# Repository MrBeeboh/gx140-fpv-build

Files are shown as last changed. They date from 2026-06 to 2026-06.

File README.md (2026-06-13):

# FPV Drone Fleet Project — Master Index
**Location:** `/home/mike/projects/Drone Projects/`
**Generated:** 2025-12-12
**Last Updated:** 2025-12-12
**Verification:** Claude Code `--chrome` researcher validated SBC/motor/GPS/radio dimensions against manufacturer wikis, DXF files, and datasheets. Mounting patterns corrected (Matek 25×25 M2, Rock 5C 86×56mm).

---

## DIRECTORY STRUCTURE

```
/home/mike/projects/Drone Projects/
├── inventory/
│   └── fleet_inventory.md          # Complete parts inventory (119 line items)
├── sbc/
│   └── sbc_deployment_checklist.md # SBC companion computer deployment
├── hardware/
│   └── hardware_reference.md       # Dimensions, pinouts, fitment data
├── cad/
│   └── mounts.scad                 # OpenSCAD parametric mounts
├── wiring/
│   └── wiring_diagrams.md          # Pin-to-pin tables, KiCad netlist
├── assembly/
│   └── assembly_sheets.md          # Step-by-step build sheets
└── docs/
    └── (future: flight logs, tuning notes, etc.)
```

---

## QUICK NAVIGATION

### Inventory & Status
| Document | Purpose | Key Data |
|---|---|---|
| `inventory/fleet_inventory.md` | Complete BOM | 6 builds, 119 items, gaps, priority orders |
| `inventory/fleet_inventory.md` | Walksnail ecosystem | Complete (Avatar Pro, Mini 1S, Goggles X, Patch V2) |

### SBC Companion Computers
| Document | Purpose | Key Data |
|---|---|---|
| `sbc/sbc_deployment_checklist.md` | Deploy Rock 5C ×2, Zero 3W, VIM4 | Hardware, software, power, cooling, model perf |

### Mechanical & CAD
| Document | Purpose | Key Data |
|---|---|---|
| `cad/mounts.scad` | 3D printable mounts | Rock 5C, Zero 3W, VIM4, cameras, wire channels |
| `hardware/hardware_reference.md` | Fitment bible | All dims, pinouts, clearance rules, thermal limits |

### Electrical & Wiring
| Document | Purpose | Key Data |
|---|---|---|
| `wiring/wiring_diagrams.md` | Wire-by-wire | SBC↔FC UART, power distro, KiCad netlist, test matrix |

### Build Instructions
| Document | Purpose | Key Data |
|---|---|---|
| `assembly/assembly_sheets.md` | Step-by-step | 6 builds, torque specs, pre-flight checklist |

---

## BUILD STATUS SUMMARY

| # | Build | Frame | Status | Blocker |
|---|---|---|---|---|
| 1 | **5" Analog Freestyle** | Mark5 HD (3D printed) | **READY** | Need Source One V5 carbon frame |
| 2 | **5" DJI O4 Cinematic** | Mario 5 O4 XH | **BLOCKED** | **DJI O4 Pro Air Unit ($150)** |
| 3 | **3" Analog Freestyle** | GX140 140mm | **READY** | Zero 3W header solder |
| 4 | **2-2.5" Whoop** | Mobula8 ×2 | **RTF** | Bind only |
| 5 | **7" Long Range** | FPVDrone 295mm | **PENDING** | FC decision: Matek H743 + singles vs MicoAir AIO |
| 6 | **450mm Platform** | YoungRC / HAWK'S WORK | **READY** | Pick FC |

### SBC Deployment Status
| SBC | Qty | Status | Next Step |
|-----|-----|---|---|
| Radxa Rock 5C Lite 16GB | 2 | Have | Mounts, heatsinks, NVMe, BEC |
| Radxa Zero 3W 4GB | 1 | Have | **Solder 40-pin header**, mount |
| Khadas VIM4 8+32GB | 1 | Have | Active cooler, NVMe, 12V supply |

### Priority Shopping List
| # | Item | Qty | Est $ | For |
|---|---|-----|---|-----|
| 1 | Source One V5 5" Frame | 1 | $80 | Build 1 (replace 3D printed) |
| 2 | DJI O4 Pro Air Unit | 1 | $150 | Build 2 (unblock) |
| 3 | SpeedyBee 50A/60A 4in1 3-6S | 3 | $45 | Build 1, spare |
| 4 | VIFLY ShortSaver | 1 | $15 | **Safety — all builds** |
| 5 | Rock 5C PCIe M.2 adapter + NVMe 256GB | 2 | $35 | SBC model storage |
| 6 | Rock 5C Heatsink + Fan | 2 | $25 | Sustained NPU |
| 7 | 5V 5A BEC (Matek/Pololu) | 2 | $30 | Rock 5C power |
| 8 | 40-pin Header + Solder (Zero 3W) | 1 | $5 | GPIO access |
| 9 | VIM4 Cooler + 12V Supply + NVMe 512GB | 1 | $60 | HDMI capture |
| 10 | OVONIC 6S 1300mAh 100C+ | 6 | $25 | 6S depth |

---

## KEY TECHNICAL SPECS (QUICK REF)

### SBC Compute
| SBC | NPU | Best Model | FPS (YOLOv11n) | Power |
|-----|-----|---|---|---|
| Rock 5C (RK3588S2) | **6 TOPS** | 8B LLM, Seg, Depth | **120 FPS** | 5V 5A |
| Zero 3W (RK3566) | **~1 TOPS** | YOLOv11n, Flow, KWS | **20 FPS** | 5V 1A |
| VIM4 (A311D2) | **3.2 TOPS** | YOLOv11s, Post-flight heavy | **65 FPS** | 12V 2A |

### Critical Wiring (Rock 5C → FC)
| Rock 5C Pin | Signal | FC Port | Wire |
|---|---|---|---|
| 2,4 (5V) | Power | BEC 5V | 22 AWG red |
| 6,9,14... (GND) | Ground | BEC GND | 22 AWG black |
| 8 (UART2_TX) | MSP TX | UART2_RX | 26 AWG |
| 10 (UART2_RX) | MSP RX | UART2_TX | 26 AWG |

### Critical Wiring (Zero 3W → FC)
| Zero 3W Pin | Signal | FC Port | Wire |
|---|---|---|---|
| 2,4 (5V) | Power | FC 5V BEC | 22 AWG red |
| 6 (GND) | Ground | FC GND | 22 AWG black |
| 8 (UART2_TX) | MSP TX | UART2_RX | 26 AWG |
| 10 (UART2_RX) | MSP RX | UART2_TX | 26 AWG |
| 3/5 (I2C) | Optical Flow | I2C1 | 28 AWG |

---

## NEXT ACTIONS (This Week)

### Monday-Tuesday: Hardware Procurement
- [ ] Order Source One V5 frame
- [ ] Order DJI O4 Pro Air Unit
- [ ] Order SpeedyBee 60A 4in1 ×3
- [ ] Order VIFLY ShortSaver
- [ ] Order Rock 5C PCIe adapters + NVMe
- [ ] Order Rock 5C heatsinks ×2
- [ ] Order 5V 5A BECs ×2
- [ ] Order Zero 3W header + solder

### Wednesday-Thursday: SBC Prep
- [ ] Flash Radxa Debian 12 on Rock 5C ×2
- [ ] Flash Radxa Debian on Zero 3W (after header solder)
- [ ] Flash Khadas Ubuntu 22.04 on VIM4
- [ ] Install RKNPU2 toolkit on Rock 5Cs
- [ ] Install NN SDK on VIM4
- [ ] Bench test YOLOv11n on Rock 5C (verify 120 FPS)

### Friday: Assembly Starts
- [ ] Build 3" GX140 (Zero 3W) — simplest, validates SBC→FC link
- [ ] Build 5" Mark5 (Rock 5C #1) — main freestyle
- [ ] Test MSP telemetry both builds
- [ ] Smoke stopper every build

### Weekend: Ground Station
- [ ] VIM4: Cooler + NVMe + 12V supply
- [ ] Test HDMI IN from Walksnail Goggles X
- [ ] GStreamer capture pipeline
- [ ] Stream to phone/PC

---

## FILE REFERENCES FOR CODE GENERATION

When you need to generate code later:
- **MSP Bridge (Python):** `wiring/wiring_diagrams.md` → UART tables
- **YOLO RKNN Quantize:** `sbc/sbc_deployment_checklist.md` → model perf table
- **GStreamer Pipeline:** `sbc/sbc_deployment_checklist.md` → VIM4 HDMI section
- **OpenSCAD Mounts:** `cad/mounts.scad` → render STLs
- **KiCad Schematic:** `wiring/wiring_diagrams.md` → netlist section
- **Assembly:** `assembly/assembly_sheets.md` → step-by-step

---

## CONTACT / NOTES
- **User:** Mike (Harold persona)
- **Platform:** HAL2026 (dual Arc B70, 64GB RAM)
- **FPV Style:** Freestyle + Long Range + Cinematic
- **Radio:** RadioMaster Boxer Crush + Pocket (ELRS)
- **Goggles:** Walksnail Goggles X (primary), EV800D (analog backup)
- **Safety:** Smoke stopper mandatory, props off for motor test

---

*End of Index — all project docs in `/home/mike/projects/Drone Projects/`*

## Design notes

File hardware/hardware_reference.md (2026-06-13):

# FPV Hardware Reference — Dimensions, Pinouts, Fitment Data
**Generated:** 2025-12-12

---

## FRAME SPECIFICATIONS

| Frame | Wheelbase | Stack | Arm | Weight | Camera Mount | Notes |
|---|---|---|-----|---|---|---|
| **Source One V5** (need) | 220mm | 30.5×30.5 | 5mm | ~90g | 20×20 / 19×19 | Standard 5" |
| **Mark5 HD** (3D printed) | 230mm | 30.5×30.5 | 5mm | ~120g | 20×20 | **Replace with carbon** |
| **Mario 5 O4 XH** | 226mm | 30.5×30.5 | 4mm | ~85g | DJI O4 specific | Cinematic |
| **GX140** | 140mm | 20×20 | 3mm | ~45g | Runcam Split / Turtle V2 | 3" |
| **Mobula8** | 85mm | 16×16 (AIO) | 2mm | ~18g | Built-in | 2" whoop |
| **Mobula7 V3** | 75mm | 16×16 (AIO) | 2mm | ~15g | Built-in | 2" whoop spare |
| **FPVDrone 295mm** | 295mm | 30.5×30.5 | 5mm | ~140g | 20×20 | 7" long range |
| **YoungRC F450** | 450mm | 30.5×30.5 | 4mm | ~280g | 30×30 | 450 class |
| **HAWK'S WORK F450** | 450mm | 30.5×30.5 | 4mm | ~280g | 30×30 | 450 class |

### Frame Mounting Patterns
| Pattern | Hole Spacing | Hole Dia | Typical Use |
|---|---|---|---|
| 16×16 | 16mm | 2.0mm | Whoop AIO |
| 20×20 | 20mm | 2.5mm | 3-4" 20×20 stack |
| 30.5×30.5 | 30.5mm | 3.2mm (M3) | 5-7" standard |
| 30×30 | 30mm | 3.2mm | 450mm platform |

---

## FLIGHT CONTROLLER SPECS

| FC | MCU | IMU | Baro | OSD | UARTs | I2C | Mount | Dim (mm) | Weight |
|----|-----|-----|---|-----|---|-----|---|---|---|
| **Radiolink F405** | STM32F405 | ICM42688 | DPS310 | Yes | 6 | 2 | 30.5 | 36×36 | 6g |
| **SpeedyBee F405 Mini** | STM32F405 | ICM42688 | DPS310 | Yes | 4 | 1 | 20×20 | 25×25 | 4g |
| **SpeedyBee F405 Mini Stack** | F405 + BLS 35A | ICM42688 | DPS310 | Yes | 4 | 1 | 20×20 | 25×25 | 12g |
| **GoolRC GF30F722** | STM32F722 | ICM42688 | DPS310 | Yes | 6 | 2 | 30.5 | 36×36 | 6g |
| **SoloGood F722 Stack** | STM32F722 | ICM42688 | DPS310 | Yes | 4 | 1 | 30.5 | 36×36 | 15g |
| **Matek H743-WLITE** | STM32H743 | ICM42688-P | DPS310 | Yes | 6 | 2 | **25×25 M2** | 36×36 | 7g |
| **MicoAir H743V2 AIO** | STM32H743 | ICM42688×2 | DPS310 | Yes | 6 | 2 | 30.5 | 45×45 | 25g |

---

## ESC SPECIFICATIONS

| ESC | Current | Protocol | Mount | Dim (mm) | Weight | BEC |
|-----|---|---|---|---|---|-----|
| **Radiolink FLYCOLOR 55A** | 55A | DShot600 | 30.5 | 36×36 | 8g | 5V 2A |
| **SpeedyBee BLS 35A** | 35A | DShot600 | 20×20 | 25×25 | 5g | 5V 3A |
| **SoloGood BLS8 60A** | 60A | DShot600 | 30.5 | 36×36 | 10g | 5V 3A |
| **HGLRC Specter 60A** | 60A | DShot600 | 30.5×30.5 4in1 | 36×36 | 8g | 5V 2A |
| **Readytosky 40A** | 40A | DShot600 | Single | 24×18 | 4g | 5V 3A |
| **AERO SELFIE 30A** | 30A | DShot600 | 30.5 | 36×36 | 5.4g | None |

---

## MOTOR SPECIFICATIONS

| Motor | Size | KV | Stator | Shaft | Mount | Weight | Prop | Cell |
|---|---|-----|---|---|---|---|---|---|
| **Axisflying 2207** | 2207 | 1850 | 22×7 | 5mm | M5 | 32g | 5" | 6S |
| **NEEBRC 2807** | 2807 | 1300 | 28×7 | 5mm | M5 | 52g | 7-10" | 6S |
| **HGLRC Specter 1804** | 1804 | 3500 | 18×4 | 4mm | M3 | 18g | 3-3.5" | 4S |
| **AKK 1407** | 1407 | 3500 | 14×7 | 4mm | M3 | 12g | 3" | 3-4S |
| **HGLRC Specter 1303.5** | 1303.5 | 5500 | 13×3.5 | 1.5mm | M2 | 6g | 2-2.5" | 2-4S |
| **Happymodel EX1103** | 1103 | 11000 | 11×3 | 1.5mm | M2 | 3.5g | 2" | 1-2S |
| **Readytosky 2212** | 2212 | 920 | 22×12 | 5mm | M5 | 48g | 10" | 4S |

---

## VTX SPECIFICATIONS

| VTX | Power | Protocol | Mount | Dim (mm) | Weight | Antenna |
|-----|---|---|---|---|---|---|
| **AKK A1918** | 200-1000mW | SmartAudio | 20×20 / M3 | 36×36 | 8g | SMA |
| **HGLRC Zeus 350mW** | 25-350mW | SmartAudio | 16×16 / M2 | 20×20 | 4g | SMA |
| **Walksnail Avatar Pro** | 400mW | Proprietary | 20×20 | 30×30 | 9g | Dual UFL |
| **Walksnail Avatar HD Mini 1S** | 200mW | Proprietary | 16×16 | 20×20 | 4.5g | Single UFL |
| **DJI O4 Pro** | 400mW | Proprietary | Custom | 30×30 | 8.5g | Dual UFL |

---

## CAMERA SPECIFICATIONS

| Camera | Sensor | Resolution | FOV | Mount | Dim (mm) | Weight | Voltage |
|---|---|---|-----|---|---|---|---|
| **Foxeer Razer Mini V3** | 1/3" CMOS | 1200TVL | 160° | 14×14 | 14×14 | 2.5g | 5V |
| **Caddx Ant** | 1/3" CMOS | 1200TVL | 160° | 14×14 | 14×14 | 2g | 5V |
| **RunCam Racer Nano 4** | 1/3" CMOS | 1200TVL | 160° | 14×14 | 14×14 | 3g | 5V |
| **Readytosky 1200TVL** | 1/3" CMOS | 1200TVL | 160° | 14×14 | 14×14 | 2.5g | 5V |
| **Walksnail Avatar Pro** | 1/1.8" Starvis 2 | 1080p60 | 160° | Custom | 30×30 | 9g | 5V |
| **Walksnail Avatar HD Mini 1S** | 1/3" CMOS | 1080p60 | 160° | 14×14 | 14×14 | 4.5g | 5V |

---

## RX SPECIFICATIONS

| RX | Protocol | Diversity | Mount | Dim (mm) | Weight | Antenna |
|----|---|---|---|---|---|---|
| **BETAFPV SuperD V3** | ELRS 2.4GHz | Yes | 20×20 / M3 | 20×20 | 3.5g | Dual UFL |
| **RadioMaster RP3** | ELRS 2.4GHz | No | 16×16 | 16×16 | 1.5g | Single UFL |
| **RadioMaster RP1** | ELRS 2.4GHz | No | 16×16 | 16×16 | 1.5g | Single UFL |
| **HGLRC ELRS Nano** | ELRS 2.4GHz | No | 16×16 | 16×16 | 1.5g | Single UFL |

---

## RADIO SPECIFICATIONS

| Radio | Protocol | Gimbals | Channels | RF Module | Battery |
|---|---|---|---|---|---|
| **RadioMaster Boxer Crush** | ELRS 2.4GHz | AG01 Hall | 16 | Internal | 18650×2 |
| **RadioMaster Pocket** | ELRS 2.4GHz | Hall | 12 | Internal | 18650×1 |

---

## GOGGLES SPECIFICATIONS

| Goggles | Type | Resolution | FOV | HDMI | DVR | Battery | Weight |
|---|---|---|-----|---|-----|---|---|
| **EV800D** | Analog | 800×480 | 82° | No | Yes | 2S LiPo | 180g |
| **Walksnail Avatar HD Goggles X** | Digital (Walksnail) | 1920×1080 | 50° | **IN/OUT** | Yes | 2S LiPo | 280g |

---

## GPS/COMPASS SPECIFICATIONS

| Module | GNSS | Compass | Mount | Dim (mm) | Weight | Protocols |
|---|---|---|---|---|---|---|
| **HGLRC M100-5883** | UBLOX M10 | QMC5883L | 20×20 / M3 | 25×25 | 8g | UBX/NMEA |
| **Matek M10Q-5883** | UBLOX M10 | QMC5883L | 20×20 / M3 | 25×25 | 8g | UBX/NMEA |
| **MicroAir M10G** | UBLOX M10 | QMC5883L | 20×20 | 25×25 | 8g | UBX/NMEA |
| **SEQURE M10-25Q** | UBLOX M10 | QMC5883L | 20×20 | 25×25 | 8g | UBX/NMEA |
| **FPVDrone M8N** | UBLOX M8 | Internal | 20×20 | 25×25 | 8g | UBX/NMEA |

---

## BATTERY SPECIFICATIONS

| Battery | Cells | Capacity | Voltage | C-Rate | Connector | Weight | Use |
|---|---|---|---|---|---|---|-----|
| **OVONIC 6S 1300mAh** | 6S | 1300mAh | 22.2V | 130C | XT60 | 210g | 5" 6S |
| **HRB 6S 1800mAh** | 6S | 1800mAh | 22.2V | 50C | XT60 | 250g | 5" 6S |
| **OVONIC 4S 4500mAh** | 4S | 4500mAh | 14.8V | 50C | T-Plug | 420g | 7" / 450mm |
| **HRB 4S 4000mAh** | 4S | 4000mAh | 14.8V | 60C | XT60 | 380g | 450mm |
| **HRB 4S 5000mAh** | 4S | 5000mAh | 14.8V | 50C | XT60 | 450g | 450mm |
| **OVONIC 2S 850mAh** | 2S | 850mAh | 7.4V | 120C | XT30 | 55g | 3" |
| **BETAFPV Lava 2S 550mAh** | 2S | 550mAh | 7.6V | 75C | XT30 | 35g | 2-3" |
| **CNHL 2S 450mAh LiHV** | 2S | 450mAh | 7.6V | 70C | XT30 | 28g | 2-3" |
| **GNB 1S 550mAh** | 1S | 550mAh | 3.7V | 90C | BT2.0 | 14g | Whoop |
| **ZEVORO 1S 450mAh LiHV** | 1S | 450mAh | 3.8V | 95C | BT2.0 | 12g | Whoop |

---

## SBC SPECIFICATIONS (DETAILED)

| SBC | SOC | CPU | NPU | GPU | RAM | Storage | PCIe | HDMI | GPIO | Dim (mm) | Weight | Power |
|-----|-----|-----|-----|-----|-----|---|---|---|---|---|---|---|
| **Radxa Rock 5C Lite** | RK3588S2 | 4×A76 + 4×A55 | **6 TOPS** | Mali-G610 MP4 | 16GB LPDDR4X | MicroSD | 2.1 x1 (E-key) | 8K@60 | 40-pin | 56×85 | 45g | 5V 5A |
| **Radxa Zero 3W** | RK3566 | 4×A55 | **~1 TOPS** | Mali-G52 2EE | 4GB LPDDR4X | MicroSD | None | 1080p@60 | 40-pin (castellated) | 45×45 | 15g | 5V 1A |
| **Khadas VIM4** | A311D2 | 4×A73 + 4×A53 | **3.2 TOPS** | Mali-G52 MP6 | 8GB LPDDR4X | 32GB eMMC + M.2 2280 | None | **IN 4K@60 / OUT 4K@60** | 40-pin | 82×58 | 45g | 12V 2A |

---

## CONNECTOR PINOUTS (QUICK REF)

### JST-GH 1.25mm (FC↔SBC, GPS, I2C)
| Pin | Signal | Wire |
|-----|---|---|
| 1 | 5V | 22 AWG red |
| 2 | TX | 26 AWG yellow |
| 3 | RX | 26 AWG white |
| 4 | SDA | 28 AWG blue |
| 5 | SCL | 28 AWG green |
| 6 | GND | 22 AWG black |

### JST-SH 1.0mm (ESC, Camera, LED)
| Pin | Signal | Wire |
|-----|---|---|
| 1 | GND | 22 AWG black |
| 2 | Signal | 26 AWG |
| 3 | 5V | 22 AWG red |
| 4 | — | — |

### XT60 / XT30
| Connector | Pin | Wire |
|---|-----|---|
| XT60 | + | 14 AWG red |
| XT60 | - | 14 AWG black |
| XT30 | + | 18 AWG red |
| XT30 | - | 18 AWG black |

---

## FITMENT CLEARANCE RULES

| Component | Clearance Required | Check Method |
|---|---|---|
| Prop to frame | ≥ 3mm | Measure at closest point |
| Prop to motor wire | ≥ 2mm | Visual |
| Prop to SBC heatsink | ≥ 5mm | Measure at max RPM |
| Battery strap to FC | ≥ 2mm | Visual |
| Antenna to carbon | ≥ 5mm | Measure |
| Camera lens to prop arc | ≥ 10mm | Visual |
| VTX antenna to RX antenna | ≥ 20mm | Measure |
| ESC to frame (single) | ≥ 3mm | Visual |
| Wire bundle to moving parts | ≥ 2mm | Visual |

---

## THERMAL LIMITS

| Component | Max Safe Temp | Throttle Point | Shutdown |
|---|---|---|---|
| RK3588S2 (Rock 5C) | 85°C | 80°C | 95°C |
| RK3566 (Zero 3W) | 80°C | 75°C | 90°C |
| A311D2 (VIM4) | 85°C | 80°C | 95°C |
| STM32F4/F7/H7 | 105°C | 100°C | 110°C |
| ESC (BLS) | 100°C | 95°C | 110°C |
| Motors | 80°C | — | 100°C |
| LiPo (discharge) | 60°C | — | 80°C |
| LiPo (charge) | 45°C | — | 50°C |

---

## WIRE CURRENT CAPACITY (Silicone Wire)

| AWG | Max Continuous | Max Burst (10s) | Use |
|-----|---|---|-----|
| 14 AWG | 32A | 50A | Main battery (XT60) |
| 16 AWG | 22A | 35A | ESC power (single) |
| 18 AWG | 16A | 25A | XT30 battery |
| 20 AWG | 11A | 18A | 5V BEC output |
| 22 AWG | 7A | 12A | SBC power, servo |
| 24 AWG | 5A | 8A | LED, beeper |
| 26 AWG | 3A | 5A | Signals (UART, I2C) |
| 28 AWG | 2A | 3A | I2C, sensors |
| 30 AWG | 1.5A | 2A | High-density signals |

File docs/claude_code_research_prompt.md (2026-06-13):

# Drone Project Dimensional Research — Claude Code Prompt
# Run with: claude --chrome -p "$(cat this_file.txt)"
# Or interactively: claude --chrome then paste the prompt below

---

## MISSION
Extract exact dimensions, mounting patterns, pinouts, and specifications for every component in my FPV drone fleet. Output as structured markdown tables with mm measurements, verified from manufacturer datasheets and documentation.

## COMPONENTS TO RESEARCH

### 1. RADXA ROCK 5C LITE (RK3588S2) — 2 units
- URL: https://wiki.radxa.com/Rock5/5c
- Need: PCB dimensions (L×W×H mm), mounting hole positions (x,y from origin), hole diameter, GPIO pinout (all 40 pins with function names), weight, power specs (voltage/current range), thermal limits, MIPI CSI pinout, PCIe connector type and location
- Verify against: https://dl.radxa.com/rock5/5c/

### 2. RADXA ZERO 3W (RK3566) — 1 unit  
- URL: https://wiki.radxa.com/Zero3w
- Need: Same as above — PCB dims, mounting holes, GPIO pinout, weight, power, MIPI CSI
- Castellations: pin pitch and arrangement for soldering 40-pin header

### 3. KHADAS VIM4 (A311D2) — 1 unit
- URL: https://docs.khadas.com/products/sbc/vim4/start
- Need: PCB dims, mounting holes, GPIO pinout, HDMI IN specifications, power (12V barrel), active cooler dimensions, NVMe M.2 slot length
- Verify: https://dl.khadas.com/products/vim4/specs/

### 4. FRAMES (all 7)
| Frame | URL to search |
|---|---|
| Source One V5 5" | Search: "TBS Source One V5 frame dimensions 3D print" |
| iFlight Mark5 HD 5" | Search: "iFlight Mark5 HD frame specs dimensions mounting" |
| GX140 140mm 3" | Search: "GX140 frame dimensions 140mm 3 inch FPV" |
| Mario 5 O4 5" | Search: "Mario 5 O4 frame 226mm DJI O4 specs" |
| FPVDrone 295mm 7" | Search: "FPVDrone 295mm 7 inch frame dimensions" |
| F450 clone 450mm | Standard — 450mm wheelbase, 30.5×30.5 stack |

### 5. FLIGHT CONTROLLERS
| FC | Search terms |
|----|---|
| Radiolink F405 | "Radiolink F405 flight controller pinout dimensions" |
| SpeedyBee F405 Mini Stack | "SpeedyBee F405 Mini 20x20 dimensions pinout" |
| GoolRC GF30F722 | "GoolRC F722 flight controller 30x30 pinout" |
| SoloGood F722 60A Stack | "SoloGood F722 60A stack dimensions pinout" |
| Matek H743-WLITE | https://www.mateksys.com/?portfolio=h743-wlite |
| MicoAir H743V2 AIO | "MicoAir743V2 AIO flight controller specs" |

### 6. ESCs  
| ESC | Search terms |
|-----|---|
| Radiolink FLYCOLOR 55A 4in1 | "Flycolor 55A 4in1 ESC 30x30 dimensions" |
| SoloGood BLS8 60A 4in1 | "SoloGood 60A BLS8 4in1 ESC specs" |
| SpeedyBee BLS 35A (20×20) | Standard 20×20 4in1 dimensions |
| HGLRC Specter 60A single | "HGLRC Specter 60A ESC dimensions weight" |
| Readytosky 40A singles | "Readytosky 40A brushless ESC dimensions" |

### 7. MOTORS — mounting pattern + weight + can dimensions
| Motor | Search |
|---|---|
| Axisflying 2207 1850KV | "Axisflying 2207 dimensions weight mounting pattern" |
| NEEBRC 2807 1300KV | "NEEBRC 2807 1300KV motor specs weight" |
| HGLRC Specter 1804 3500KV | "HGLRC Specter 1804 dimensions weight" |
| AKK 1407 3500KV | "AKK 1407 motor dimensions weight" |
| HGLRC Specter 1303.5 5500KV | "HGLRC 1303.5 motor dimensions weight" |
| Happymodel EX1103 11000KV | "EX1103 11000KV motor specs" |
| Readytosky 2212 920KV | Standard 2212 dimensions |

### 8. VTX / CAMERAS / RX
| Component | Search |
|---|---|
| AKK A1918 VTX | "AKK A1918 5.8G VTX dimensions pinout" |
| HGLRC Zeus 350mW | "HGLRC Zeus VTX specs dimensions" |
| Walksnail Avatar Pro | "Walksnail Avatar Pro dimensions weight mounting" |
| Walksnail Avatar HD Mini 1S | "Walksnail Avatar Mini 1S lite kit specs" |
| Foxeer Razer Mini V3 | "Foxeer Razer Mini V3 camera dimensions" |
| Caddx Ant camera | "Caddx Ant FPV camera dimensions weight" |
| RunCam Racer Nano 4 | "RunCam Racer Nano 4 dimensions" |
| BETAFPV SuperD ELRS Diversity RX | "BETAFPV SuperD ELRS diversity receiver dimensions" |
| RadioMaster RP3 ELRS RX | "RP3 ELRS receiver dimensions weight" |

### 9. RADIOS / GOGGLES / GPS
| Component | Search |
|---|---|
| RadioMaster Boxer Crush | "RadioMaster Boxer dimensions screen resolution weight" |
| RadioMaster Pocket | "RadioMaster Pocket dimensions weight" |
| EV800D Goggles | "EV800D FPV goggles dimensions weight" |
| Walksnail Goggles X | "Walksnail Avatar Goggles X specs dimensions weight" |
| HGLRC M100-5883 GPS | "HGLRC M100 GPS module dimensions weight" |
| Matek M10Q-5883 | "Matek M10Q-5883 GPS dimensions" |
| MicroAir M10G | "MicroAir M10G GPS module specs" |
| SEQURE M10-25Q | "SEQURE M10Q GPS module dimensions" |
| FPVDrone M8N GPS | "FPVDrone M8N GPS module specs" |

## OUTPUT FORMAT

For each component, provide this exact table structure:

```markdown
### [COMPONENT NAME]
| Property | Value | Source |
|----------|-------|--------|
| Dimensions (L×W×H mm) | | |
| Weight (g) | | |
| Mounting Pattern (mm) | | |
| Mounting Hole Dia (mm) | | |
| Power (V/A) | | |
| Pinout / Ports | | |

**Pinout Table (if applicable):**
| Pin | Function | Notes |
|-----|----------|-------|
```

## RULES
1. Extract EXACT numbers from manufacturer pages — do not estimate
2. If a dimension cannot be found, mark as "NOT FOUND — [what was searched]"
3. For FPV standard sizes (30.5×30.5, 20×20, 16×16), verify against manufacturer
4. Include direct URLs to source pages for every number
5. Prefer manufacturer wiki/docs over 3rd party reviews
6. For GPIO pinouts, include the linux GPIO number (e.g., GPIO14, GPIO15)
7. Metric units only (mm, g, V, A)
8. When you find a full specification PDF, download and parse it

## PRIORITY ORDER
Research in this order — these are the most critical for fitment:
1. Rock 5C Lite (will ride on 5" and 7" builds — must fit)
2. Source One V5 frame + Mario 5 O4 (primary frames)
3. Matek H743-WLITE + SpeedyBee F405 Mini (primary FCs)
4. NEEBRC 2807 + Axisflying 2207 + EX1103 motors
5. Walksnail Goggles X + VIM4 ground station
6. Remaining components as time allows

## SAVE OUTPUT
Save complete results to: `/home/mike/projects/Drone Projects/hardware/verified_dimensions.md`

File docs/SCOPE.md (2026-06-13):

# FPV Drone Fleet — Project Scope & Build Plan
**Version:** 1.0  
**Date:** 2025-12-12  
**Owner:** Mike  
**Status:** Planning Complete — Procurement Blocked  

---

## 1. EXECUTIVE SUMMARY

Six-aircraft FPV fleet with onboard AI companion computers (Rock 5C, Zero 3W) and a ground-based video processing station (Khadas VIM4). Analog + Walksnail HD dual ecosystem. ELRS control. Betaflight configuration with GPS rescue on all builds ≥3".

**Total builds:** 6  
**SBC companions:** 3  
**Ground station:** 1  
**Current state:** 80% parts in hand, 20% procurement needed  

---

## 2. WHAT WE'RE BUILDING

| # | Build | Class | Role | FC | VTX | SBC | Status |
|---|---|---|---|-----|-----|-----|---|
| 1 | **5" Analog Freestyle** | 5" 6S | Daily flyer, CV testbed | Radiolink F405 + 55A 4in1 | AKK A1918 (analog) | Rock 5C #1 | Parts ready, need carbon frame |
| 2 | **5" Walksnail HD Cinematic** | 5" 6S | Cinematic, HD recording | SoloGood F722 + 60A BLS8 | Walksnail Avatar Pro (have) | None | Parts ready — use Walksnail, NOT DJI |
| 3 | **3" Analog Freestyle** | 3" 3-4S | Proximity, indoor CV | SpeedyBee F405 Mini + 35A 4in1 | HGLRC Zeus 350mW (analog) | Zero 3W | Parts ready, need header solder |
| 4 | **2-2.5" Whoop** (×2) | 85mm 1-2S | Indoor, proximity | X12 AIO (built-in) | Built-in | None | RTF — bind only |
| 5 | **7" Long Range** | 7" 4-6S | LR, GPS rescue, CV | Matek H743-WLITE + 40A singles | AKK A1918 (analog) | Rock 5C #2 | FC decision pending |
| 6 | **450mm Platform** | 450mm 4S | Payload, mapping | GoolRC F722 / Matek H743 | AKK A1918 (analog) | None | Parts ready |
| — | **Ground Station** | Desktop | HDMI capture + record | — | Walksnail Goggles X input | Khadas VIM4 | Need cooler + NVMe |

---

## 3. SCOPE BOUNDARIES

### IN SCOPE
- [x] FPV aircraft assembly (frame, stack, motors, VTX, cam, RX)
- [x] SBC companion computer integration (Rock 5C, Zero 3W)
- [x] FC↔SBC UART telemetry bridge (MSP/MAVLink)
- [x] Betaflight 2025.12 configuration (rates, filters, GPS rescue, OSD)
- [x] ELRS binding, failsafe, GPS rescue testing
- [x] Ground station HDMI capture pipeline (VIM4)
- [x] 3D printed mounts for SBC integration
- [x] Wire harness fabrication with verified pinouts
- [x] Pre-flight safety checks (smoke stopper mandatory)
- [x] Maiden flights + tuning

### OUT OF SCOPE (v1)
- [ ] Autonomous flight / waypoint missions (v2)
- [ ] Real-time object detection during flight (v2 — needs model quantization)
- [ ] Live video streaming from Rock 5C (v2 — needs MIPI camera)
- [ ] Drone-to-drone communication (v3)
- [ ] Swarm / formation flight (v3)
- [ ] DJI O3/O4 ecosystem (user chose Walksnail — incompatible)
- [ ] Custom PCB design for SBC↔FC interface (using JST-GH wires for v1)
- [ ] Long-range 900MHz (ELRS 2.4GHz only for v1)

---

## 4. DEPENDENCIES & BLOCKERS

### Critical Path — MUST ORDER
| # | Item | Qty | Est $ | Blocks Build(s) | Priority |
|---|---|-----|---|---|---|
| 1 | **Source One V5 5" carbon frame** | 1 | $80 | #1 (5" Analog) | P0 |
| 2 | **VIFLY ShortSaver smoke stopper** | 1 | $15 | ALL (safety) | P0 |
| 3 | **40-pin header 2.54mm + solder** | 1 | $5 | #3 (Zero 3W GPIO) | P0 |
| 4 | **DJI O4 Pro Air Unit** | 1 | $150 | #2 (5" DJI) | P1 |
| 4 | **Rock 5C PCIe M.2 adapter + NVMe 256GB** | 2 | $70 | SBC deploy | P1 |
| 5 | **Rock 5C active heatsink + 3010 fan** | 2 | $50 | SBC deploy | P1 |
| 6 | **5V 5A BEC (Matek/Pololu)** | 2 | $30 | SBC power | P1 |
| 7 | **Matek H743 25×25→30.5 adapter plate** | 1 | $10 | #5 (7" LR) | P2 |
| 8 | **OVONIC 6S 1300mAh 100C+** | 4-6 | $150 | All 6S builds | P2 |

**Total procurement:** ~$350 (P0-P1: ~$250, P2: ~$160)

### Non-Purchase Blockers
| Blocker | Resolution | Effort |
|---|---|---|
| Zero 3W no GPIO header | Solder 40-pin header | 15 min |
| Matek H743 incompatible with 30.5mm frames | Print adapter plate or use MicoAir AIO instead | 1 hr |
| Rock 5C doesn't fit standard stack patterns | 3D print custom mount (OpenSCAD ready) | 2 hr |
| Mark5 frame is 3D printed copy | Replace with Source One V5 carbon | Purchase |
| HGLRC Specter 60A = 4in1 (corrected) | Use as 4in1, not single | 0 min |

---

## 5. BUILD SCHEDULE

### Phase 1: Tools & Parts (Week 1)
```
Day 1-2: Order items #1-7 above
Day 3-4: Install OpenSCAD, Blender, ezdxf (for mount generation)
Day 5: Zero 3W — solder 40-pin header
Day 6-7: Flash Radxa Debian 12 on Rock 5C ×2 + Zero 3W
```

### Phase 2: First Builds (Week 2)
```
Day 1: Build #3 (3" GX140 + Zero 3W) — simplest, validates SBC↔FC link
Day 2: Build #4 (Mobula8 ×2) — bind to Boxer/Pocket, set rates
Day 3: Bench test Rock 5C #1 — YOLOv11n RKNN quantization, verify 120 FPS
Day 4: Build #1 (5" Source One V5 + Rock 5C #1) — primary freestyle
Day 5: Maiden flights #1 + #3 — hover test, punch-out, PID tuning
```

### Phase 3: Advanced Builds (Week 3)
```
Day 1-2: Build #6 (450mm Platform) — payload testing, GPS rescue
Day 3: Build #5 (7" LR) — FC decision, adapter plate, GPS ×2
Day 4: Maiden flight #5 — GPS rescue validation
Day 5: Ground station — VIM4 cooler + NVMe + HDMI capture test
```

### Phase 4: Walksnail Cinematic (Week 3-4)
```
Day 1: Build #2 (Mario 5 O4 frame + Walksnail Avatar Pro) — use existing Walksnail, no DJI
Day 2: Bind Walksnail to Goggles X, camera setup
Day 3: Maiden cinematic flights, gyroflow stabilization
```

---

## 6. SUCCESS CRITERIA

### Per Build
| Build | Hover | Punch-out | GPS Lock | GPS Rescue | SBC MSP | YOLO Inference |
|---|---|---|---|---|---|---|
| #1 5" Analog | ✅ | ✅ | ✅ <60s | ✅ <15m radius | ✅ 921600 baud | ✅ >100 FPS |
| #2 5" Walksnail | ✅ | ✅ | ✅ <60s | ✅ <15m radius | N/A | N/A |
| #3 3" Analog | ✅ | ✅ | ✅ <60s | ✅ <10m radius | ✅ 921600 baud | ✅ >15 FPS |
| #4 Whoop ×2 | ✅ | ✅ | N/A | N/A | N/A | N/A |
| #5 7" LR | ✅ | ✅ | ✅ <30s | ✅ <5m radius | ✅ 921600 baud | ✅ >100 FPS |
| #6 450mm | ✅ | ✅ | ✅ <60s | ✅ <10m radius | N/A | N/A |
| Ground Station | N/A | N/A | N/A | N/A | N/A | N/A |

### Ground Station
- [ ] HDMI IN from Walksnail Goggles X → captured at 4K@60
- [ ] H.265 hardware encode → NVMe recording
- [ ] Real-time detection overlay on stream
- [ ] RTSP/WebRTC stream to phone/PC
- [ ] Post-flight model inference on recorded footage

### System-Wide
- [ ] All builds bound to Boxer Crush + Pocket (ELRS)
- [ ] All builds smoke-stopper tested before first plug
- [ ] All SBCs reachable via SSH
- [ ] All builds documented with diff + dump backups
- [ ] GPS rescue validated on all GPS-equipped builds
- [ ] Motor temps < 50°C, SBC temps < 65°C under load

---

## 7. ARCHITECTURE DIAGRAM (Text)

```
                    ┌─────────────────────────────────┐
                    │     RadioMaster Boxer Crush      │
                    │     (ELRS 2.4GHz, EdgeTX)        │
                    └────────────┬────────────────────┘
                                 │ CRSF 2.4GHz
                    ┌────────────▼────────────────────┐
                    │     BETAFPV SuperD Diversity     │
                    │     (ELRS V3, dual antenna)      │
                    └────────────┬────────────────────┘
                                 │ UART (CRSF)
                    ┌────────────▼────────────────────┐
                    │          Flight Controller        │
                    │   F405/F722/H743 + 4in1 ESC      │
                    │   Betaflight 2025.12              │
                    └──┬──────┬──────┬──────┬──────┬───┘
                       │      │      │      │      │
              ┌────────▼─┐ ┌──▼──┐ ┌─▼──┐ ┌─▼──┐ ┌─▼──────┐
              │Rock 5C #1│ │ GPS │ │VTX │ │Cam │ │ Motors │
              │(UART MSP)│ │M10Q │ │AKK │ │Fox │ │ Axisfly│
              │CV + ROS2 │ │     │ │    │ │Razr│ │ 2207   │
              └──────────┘ └─────┘ └────┘ └────┘ └────────┘

                    ┌─────────────────────────────────┐
                    │     Walksnail Goggles X V2       │
                    │     HDMI OUT ───────────────┐    │
                    └─────────────────────────────│────┘
                                                  │
                    ┌─────────────────────────────▼────┐
                    │       Khadas VIM4 (Ground)        │
                    │   HDMI IN → H.265 encode → NVMe   │
                    │   Real-time detect → stream phone │
                    └──────────────────────────────────┘
```

---

## 8. FILE INDEX (All Docs)

| File | Content | Status |
|---|---|---|
| `README.md` | Master index + next actions | ✅ |
| `inventory/fleet_inventory.md` | 119 items, 6 builds, gaps | ✅ Verified |
| `sbc/sbc_deployment_checklist.md` | SBC HW/SW/perf/power/cooling | ✅ Updated dims |
| `hardware/hardware_reference.md` | Dims, pinouts, clearance, thermal | ✅ Updated (Matek, Rock 5C) |
| `hardware/verified_dimensions.md` | Claude Code research — 759 lines | ✅ Verified |
| `cad/mounts.scad` | OpenSCAD parametric mounts | ✅ Updated PCB dims |
| `wiring/wiring_diagrams.md` | Pin-to-pin, KiCad netlist, test matrix | ✅ GPIOs verified |
| `assembly/assembly_sheets.md` | Step-by-step 6 builds, torque, pre-flight | ✅ Updated (Matek note) |
| `docs/claude_code_research_prompt.md` | Reusable research prompt | ✅ |
| `datasheets/betaflight_2025_12_cli_reference.md` | CLI reference (38 KB) | ✅ |
| `datasheets/betaflight_msp_protocol.md` | MSP protocol (223 KB) | ✅ |
| **`docs/SCOPE.md`** | **This document** | ✅ |

---

## 9. NEXT ACTION (Right Now)

The single most impactful thing you can do in the next 10 minutes:

```
Open Amazon → order these 3 items:

1. "Source One V5 5 inch frame kit carbon" → $60-80
2. "VIFLY ShortSaver 2-6S XT60 smoke stopper" → $15
3. "2.54mm 40-pin male header strip" → $5
```

That unblocks Build #1 (primary freestyle with Rock 5C), protects all future builds (safety), and gives the Zero 3W I/O it needs for Build #3.

**You do NOT need to buy DJI O4 — you own a complete Walksnail system.**

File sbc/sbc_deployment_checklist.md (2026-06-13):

# SBC FPV Companion Deployment Checklists
**Generated:** 2025-12-12

---

## RADXA ROCK 5C LITE ×2 — Primary Airborne Companion

### Specifications
| Parameter | Value |
|---|---|
| **SOC** | Rockchip RK3588S2 |
| **CPU** | 4× Cortex-A76 @ 2.4GHz + 4× Cortex-A55 @ 1.8GHz |
| **NPU** | **6 TOPS INT8** (RKNPU2) |
| **GPU** | Mali-G610 MP4 |
| **RAM** | 16GB LPDDR4X |
| **Storage** | MicroSD + PCIe 2.1 x1 (M.2 E-key) |
| **Video** | HDMI 8K@60, MIPI CSI ×2, MIPI DSI ×1 |
| **Network** | GbE, WiFi 6/BT 5.1 (module) |
| **GPIO** | 40-pin header (UART ×4, I2C ×3, SPI ×2, PWM ×4) |
| **Dimensions** | 86mm × 56mm (from Radxa wiki) |
| **Weight** | ~45g (board only) |
| **Mounting** | **Custom pattern** — does NOT fit standard 30.5×30.5 or 20×20 stacks. Needs adapter plate. Mounting holes in DXF at dl.radxa.com |

### Model Performance (RK3588S2 @ 6 TOPS INT8)
| Model | Resolution | FPS | Precision |
|---|---|-----|---|
| YOLOv11n | 640×640 | **~120 FPS** | INT8 |
| YOLOv11s | 640×640 | **~65 FPS** | INT8 |
| YOLOv8n-seg | 640×640 | **~55 FPS** | INT8 |
| DepthAnything-ViT-S | 640×640 | **~18 FPS** | INT8 |
| MobileSAM | 640×640 | **~30 FPS** | INT8 |
| LLaMA-3.2-3B-GGUF-q4 | - | **~25 tok/s** | INT4/INT8 |
| Phi-3.5-mini-GGUF-q4 | - | **~35 tok/s** | INT4/INT8 |

### Power Requirements
| State | Power | Current @ 5V |
|---|---|---|
| Idle | 2.5-3W | 0.5-0.6A |
| Full NPU | 5-7W | 1.0-1.4A |
| Peak | 8-10W | 1.6-2.0A |
| **Recommended** | **5V 5A** | **2S-6S → 5V 5A BEC** |

### Cooling
**Active mandatory.** Passive hits 85°C+ in 3 min at full NPU.
- Solution: 30×30×10mm heatsink + 5V 3010 fan = 55°C sustained
- Mount: M2.5 standoffs on 4 mounting holes (3.5mm Ø)

### FPV Integration Role
**Heavy edge inference / ROS2 navigation / Computer vision on 5-7" quads**
- ROS2 Nav2 + YOLOv11 obstacle avoidance + depth estimation
- UART/MAVLink to FC for closed-loop control
- NVMe for model storage + blackbox logs + video recording

### Hardware Needed (per unit)
- [ ] Rock 5C Lite 16GB (have 2)
- [ ] PCIe M.2 E-key → M-key adapter + NVMe 256GB+ (need)
- [ ] Active heatsink + 5V 3010 fan kit (need)
- [ ] 5V 5A BEC: Matek 5V 5A or Pololu D24V50F5 (need 2)
- [ ] MicroSD UHS-I A2 128GB+ (need 2)
- [ ] 40-pin GPIO header + right-angle for low profile (need)
- [ ] Mini HDMI → HDMI cable (for dev)
- [ ] USB-C PD trigger board or 20V→5V buck (optional)

### Software Stack
| Layer | Technology |
|---|---|
| OS | Radxa Official Debian 12 (Bookworm) + RKNPU2 toolkit |
| NPU Runtime | RKNPU2 / rknn-toolkit2 (Python/C++) |
| CV | OpenCV 4.x + GStreamer (RKMPP hardware decode) |
| Inference | rknn-toolkit2 → ONNX → RKNN quantization |
| LLM | llama.cpp (RKNPU backend) or MLC-LLM |
| ROS2 | Humble/Iron on Ubuntu 22.04/24.04 |
| Serial | pyserial / MAVLink / MSP over UART (GPIO UART2/4) |

### FC Link
- **Primary:** UART (TELEM2) → MSP/MAVLink for telemetry + control
- **Secondary:** CAN (if FC supports) for higher bandwidth
- **Baud:** 921600 (MSP) / 57600 (MAVLink)

### Camera Options
| Interface | Options | Notes |
|---|---|---|
| MIPI CSI | IMX219, IMX477, OV5647, AR0234 | Need camera module + ribbon |
| USB3 | Logitech Brio, ELP USB3, FLIR Boson | UVC/V4L2, easier integration |
| GMSL | Maxim GMSL2 serializer + IMX390 | Long cable runs, automotive grade |

### Storage
- **NVMe (PCIe):** Models + blackbox logs + video recording
- **MicroSD:** OS boot only (A2 class minimum)

---

## RADXA ZERO 3W — Lightweight Telemetry/Bridge

### Specifications
| Parameter | Value |
|---|---|
| **SOC** | Rockchip RK3566 |
| **CPU** | 4× Cortex-A55 @ 1.8GHz |
| **NPU** | **~1 TOPS INT8** |
| **GPU** | Mali-G52 2EE |
| **RAM** | 4GB LPDDR4X |
| **Storage** | MicroSD (no eMMC) |
| **Video** | HDMI 1080p@60, MIPI CSI ×1, MIPI DSI ×1 |
| **Network** | WiFi 5 + BT 5.0 (onboard) |
| **GPIO** | 40-pin castellated edges (need header solder) |
| **Dimensions** | 45mm × 45mm |
| **Weight** | ~15g (board only) |

### Power
| State | Power | Current @ 5V |
|---|---|---|
| Idle | 1.2W | 0.24A |
| Full | 2.5-3W | 0.5-0.6A |
| **Source** | **5V from FC BEC** | |

### Cooling
Passive sufficient for typical loads. Small 20×20×5mm heatsink recommended.

### FPV Integration Role
**Sensor fusion / Optical flow / Telemetry bridge / KWS on 3-5" builds**
- Optical flow (PAA5100/PMW3901) via SPI/I2C
- Precision hover, indoor nav, obstacle proximity
- WiFi/BT telemetry backup (ELRS primary)
- Keyword spotting (Porcupine/Picovoice on NPU)

### Hardware Needed
- [ ] Zero 3W 4GB (have 1, no GPIO header)
- [ ] **Solder 40-pin header** (2.54mm pitch) or use castellated edges
- [ ] MicroSD UHS-I 64GB+
- [ ] Tiny heatsink 20×20×5mm
- [ ] Optional: MIPI CSI camera (OV5647/IMX219)

### Software Stack
| Layer | Technology |
|---|---|
| OS | Radxa Debian/Ubuntu for Zero 3W |
| NPU | RKNPU2 (RK3566 support in rknn-toolkit2) |
| CV | OpenCV + libcamera (MIPI) or v4l2 (USB) |
| Inference | YOLOv8n/YOLOv11n INT8, MobileNet-SSD |
| Audio | Keyword spotting (Porcupine/Picovoice on NPU) |

---

## KHADAS VIM4 — Ground Station / Video Processor

### Specifications
| Parameter | Value |
|---|---|
| **SOC** | Amlogic A311D2 |
| **CPU** | 4× Cortex-A73 @ 2.2GHz + 4× Cortex-A53 @ 2.0GHz |
| **NPU** | **3.2 TOPS INT8** (NPU) |
| **GPU** | Mali-G52 MP6 (8EE) |
| **RAM** | 8GB LPDDR4X |
| **Storage** | 32GB eMMC + MicroSD + M.2 2280 NVMe |
| **Video** | **HDMI IN 4K@60** (unique), HDMI OUT 4K@60, MIPI CSI ×2, MIPI DSI ×1 |
| **Network** | WiFi 6 + BT 5.1, GbE |
| **GPIO** | 40-pin header |
| **Dimensions** | 82mm × 58mm |
| **Weight** | ~45g (board only) |

### Unique Feature
**HDMI IN 4K@60 → Hardware H.265 encode** — Capture goggles output directly.

### Power
| State | Power | Voltage |
|---|---|---|
| Idle | 3W | 12V/2A barrel or USB-C PD |
| HDMI Capture + Encode | 5-7W | 12V |
| Full NPU | 6-8W | 12V |

### Cooling
**Official active cooler required** for sustained HDMI capture + NPU.

### FPV Integration Role
**HDMI capture → encode → stream/record / Moderate inference on recorded footage**
- Input: HDMI IN from Walksnail/DJI/HDZero goggles
- Process: Real-time detect → overlay → re-stream to phone/PC
- Record: Full 4K60 H.265 recording of FPV feed + telemetry overlay
- Post-flight: Run heavier models (YOLOv11x, SAM2, DepthAnything) on recorded footage

### Hardware Needed
- [ ] VIM4 8+32GB (have)
- [ ] VIM4 case (have)
- [ ] **VIM4 official active cooler** (need)
- [ ] **12V 2A power supply** (barrel jack)
- [ ] **M.2 NVMe 512GB+** (need for recording)
- [ ] HDMI cable (goggles → VIM4 IN)

### Software Stack
| Layer | Technology |
|---|---|
| OS | Khadas Official Ubuntu 22.04 (Focal) / 24.04 (Noble) |
| HDMI Capture | V4L2 / GStreamer (Amlogic VPU hardware) |
| Encode | H.264/H.265 hardware encode (VPU) |
| NPU | NN SDK (3.2 TOPS, INT8/INT16/FP16) |
| Inference | YOLOv8, MobileNet, custom TFLite/ONNX → NN SDK |
| Streaming | GStreamer → RTSP/SRT/WHIP/WebRTC |
| Recording | MP4/TS via GStreamer + NVMe |

---

## IMMEDIATE NEXT STEPS (Priority Order)

| # | Task | Why |
|---|---|-----|
| 1 | Order Rock 5C PCIe M.2 adapter + NVMe 256GB | Enables model storage |
| 2 | Order 2× Rock 5C active heatsink + fan kits | Required for sustained NPU |
| 3 | Order 2× 5V 5A BEC (Matek/Pololu) for 2S-6S → 5V | Clean power from flight battery |
| 4 | Order 40-pin header for Zero 3W + solder | Enable UART/I2C/SPI for FC |
| 5 | Order VIM4 active cooler + 12V supply + M.2 NVMe 512GB | Enable HDMI capture |
| 6 | Flash Radxa Debian 12 on Rock 5C ×2 + Zero 3W | Baseline OS with RKNPU2 |
| 7 | Flash Khadas Ubuntu 22.04 on VIM4 | Baseline OS with NN SDK |
| 8 | Build MSP/MAVLink telemetry bridge (Python) on Rock 5C | FC ↔ Companion communication |
| 9 | Quantize YOLOv11n + MobileSAM to RKNN for Rock 5C | Primary CV models |
| 10 | Test HDMI IN capture on VIM4 with Walksnail goggles | Validate ground station |

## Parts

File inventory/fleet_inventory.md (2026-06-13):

# FPV Drone Fleet Inventory
**Generated:** 2025-12-12
**Source:** Amazon order history (Jun-Dec 2025) + Walksnail additions

---

## COMPLETE BUILDS READY NOW

| Build | Frame | FC/Stack | Motors | ESC | Props | RX | VTX/Cam | Battery | Status |
|---|---|---|---|-----|---|-----|---|---|---|
| **5" Analog Freestyle** | Mark5 HD (3D printed) | Radiolink F405 / SpeedyBee F405 Mini | Axisflying 2207 1850KV (4) | Radiolink 55A 4in1 | HQProp Ethix S5 5x4x3 (16) | RP3 ELRS / SuperD Diversity | AKK A1918 VTX + Foxeer Razer Mini | OVONIC 6S 1300mAh / HRB 6S 1800mAh | **READY** |
| **5" DJI O4 Cinematic** | Mario 5 O4 XH | GoolRC F722 / SoloGood F722 Stack | Axisflying 2207 1850KV (4) | SoloGood 60A 4in1 BLS8 | HQProp Ethix S5 | SuperD Diversity | **NEEDS DJI O4 Air Unit** | OVONIC 6S 1300mAh | **NEEDS O4** |
| **3" Analog Freestyle** | GX140 140mm | SpeedyBee F405 Mini Stack | HGLRC Specter 1804 3500KV (4) | SpeedyBee 35A 4in1 | GEMFAN 3052 3in (16) | RP3 ELRS / SuperD Diversity | HGLRC Zeus 350mW + Caddx Ant | BETAFPV 2S 550mAh LiHV / OVONIC 2S 850mAh | **READY** |
| **2-2.5" Toothpick/Whoop** | Mobula8 85mm / Mobula7 75mm | Built-in X12 AIO | HGLRC Specter 1303.5 5500KV (5) / EX1103 11000KV (4) | Built-in | Gemfan Hurricane 2in (16) / GEMFAN Flash 2.5in (24) | Built-in ELRS / SuperD Diversity | Built-in VTX + Caddx Ant | BETAFPV 2S 550mAh LiHV / GNB 1S 550mAh | **READY** (2x complete Mobula8) |
| **7" Long Range** | FPVDrone 295mm 7in | Matek H743-WLITE / MicoAir H743 AIO | NEEBRC 2807 1300KV (8) | Readytosky 40A singles (4) / HGLRC Specter 60A | HQProp 7x3.5x3 (8) | SuperD Diversity + RP1 backup | HGLRC Zeus / AKK A1918 + RunCam Racer Nano | HRB 4S 4000/5000mAh / OVONIC 4S 4500mAh | **NEEDS FC DECISION** |
| **450mm Platform** | YoungRC / HAWK'S WORK F450 | Matek H743 + PDB-HEX / GoolRC F722 | Readytosky 2212 920KV (4) | Readytosky 40A singles (4) | Readytosky 1045 10x4.5 (12) | RP3 ELRS / SuperD | AKK A1918 + Readytosky 1200TVL | HRB 4S 4000/5000mAh | **READY** |

---

## INVENTORY BY CATEGORY

### Flight Controllers (7)
- Radiolink F405 ×1
- SpeedyBee F405 Mini Stack ×1
- GoolRC GF30F722 F722 ×1
- SoloGood F722 Stack 60A BLS8 ×1
- Matek H743-WLITE ×1
- MicoAir743V2 AIO 45A 4in1 ×1
- GoolRC F722 FC 3-8S ×1

### ESC
- **4in1:** Radiolink FLYCOLOR 55A 3-6S ×1, SpeedyBee 35A BLS (in F405 Mini Stack) ×1, SoloGood 60A BLS8 ×1, AERO SELFIE 30A ×1, HGLRC Specter 60A ×1
- **Singles:** Readytosky 2-4S 40A 5V/3A BEC ×4

### Motors
- **6S 5-6":** Axisflying 2207 1850KV ×4, NEEBRC 2807 1300KV ×8
- **4S 3-5":** HGLRC Specter 1804 3500KV ×4, AKK 1407 3500KV ×4
- **Micro:** HGLRC Specter 1303.5 5500KV ×5, Happymodel EX1103 11000KV ×4, Readytosky 2212 920KV ×4

### Frames (7)
- Mark5 HD Analog 5" 5mm Arms (3D Printed) ×1
- GX140 140mm for Runcam Split/Caddx Turtle ×1
- Mobula8 85mm Frame (2pcs) ×1 + Mobula7 V3 75mm ×1
- Mario 5 O4 XH 5" 226mm DJI O4/O3 ×1
- FPVDrone 295mm 7" Frame 5mm Arms ×1
- YoungRC F450 450mm ×1
- HAWK'S WORK F450 450mm ×1

### VTX/Cameras
- **Analog VTX:** AKK A1918 5.8G 200-1000mW ×5, HGLRC Zeus350mW ×1
- **Digital HD:** Walksnail Avatar Pro Kit ×1, Walksnail Avatar HD Mini 1s Lite Kit ×1
- **Cameras Analog:** SoloGood Caddx Ant 1200TVL 1.8mm ×3, Foxeer Razer Mini V3 1200TVL ×1, RunCam Racer Nano 4 1200TVL ×1, Readytosky 1200TVL NTSC 2.5mm ×1

### RX/Radio
- **ELRS Nano:** HGLRC ELRS 2.4GHz ×2, RadioMaster RP3 ELRS ×1, RadioMaster RP1 ELRS ×1
- **ELRS Diversity:** BETAFPV SuperD ExpressLRS 2.4GHz V3 ×2
- **Radios:** RadioMaster Boxer Crush EdgeTX 16CH ×1, RadioMaster Pocket ELRS ×1

### Goggles
- **Analog:** EV800D FPV Goggles 5.8G 40CH ×1
- **Digital:** Walksnail Avatar HD Goggles X With Kit V2 ×1

### Antennas
- RHCP: SpeedyBee 2.8dBi ×2, Foxeer Lollipop 2.6dBi ×2
- LHCP: HGLRC Hammer 2.5dBi ×2
- Patch: 5.8GHz Triple Feed 9.4dBi ×1, Walksnail Patch Antenna V2 ×1

### Batteries
- **6S:** HRB 1800mAh 50C ×2, OVONIC 1300mAh 130C ×2
- **4S:** HRB 4000mAh 60C ×1, HRB 5000mAh 50C ×1, OVONIC 4500mAh 50C ×2
- **3S:** URGENEX 500mAh 50C ×2
- **2S:** OVONIC 850mAh 120C ×2, BETAFPV Lava 550mAh 75C LiHV ×4, CNHL 450mAh 70C LiHV ×3, Crazepony 3000mAh (goggles) ×2
- **1S:** GNB 550mAh 90C BT2.0 ×6, ZEVORO 450mAh 95C LiHV BT2.0 ×4

### GPS/Compass (8)
- HGLRC M100-5883 GPS Compass ×4
- Matek M10Q-5883 GNSS Compass ×1
- MicroAir M10G with QMC5883L ×1
- SEQURE M10-25Q GPS with QMC5883L ×1
- FPVDrone M8N GPS with Compass ×2

### SBC/Compute (4 + 1 case)
- Radxa Rock 5C Lite 16GB (RK3588S2, 6 TOPS) ×2
- Radxa Zero 3W 4GB (RK3566, ~1 TOPS) ×1
- Khadas VIM4 8+32GB (A311D2, 3.2 TOPS) ×1
- DIY Case for VIMs SBC Series ×1

### Tools/Accessories
- HobbyPark 11-in-1 RC Tools Kit ×1
- SpeedyBee BT Nano 3 Bluetooth FC Config ×1
- HGLRC Thor 40A 4-Port Balance Charger ×1
- H B6 Lipo Charger 80W 6A ×1
- BETAFPV BT2.0 1S Charger ×1
- VIFLY Beacon Buzzer ×2, FPVDrone FPV Finder Buzzer ×1
- SpeedyBee LED Strip RGB ×4
- Battery straps, silicone mats, XT60/XT30 adapters, motor screws, anti-vibration balls

---

## GAPS & PRIORITY ORDERS

| Priority | Item | Qty | Est. $ | Why |
|---|---|-----|---|-----|
| 1 | Source One V5 5" Frame (carbon) | 1 | $60-90 | Only 5" frame is 3D printed |
| 2 | SpeedyBee 50A/60A 4in1 ESC 3-6S | 2-3 | $45×3 | Need 6S 4in1 for 5" builds |
| 3 | VIFLY ShortSaver Smoke Stopper | 1 | $15 | **Safety — non-negotiable** |
| 4 | DJI O4 Pro Air Unit | 1 | $150 | For Mario 5 O4 frame |
| 5 | OVONIC 6S 1300mAh 100C+ | 4-6 | $25×6 | 6S battery depth thin |
| 6 | Prop tool / M5 wrench | 1 | $10 | Motor screws need proper tool |
| 7 | Rock 5C PCIe M.2 adapter + NVMe 256GB | 2 | $35 | SBC model storage |
| 8 | Rock 5C active heatsink + fan | 2 | $25 | Sustained NPU operation |
| 9 | 5V 5A BEC (Matek/Pololu) | 2 | $30 | Clean 2S-6S → 5V for SBCs |
| 10 | VIM4 active cooler + 12V supply + NVMe 512GB | 1 | $60 | HDMI capture enable |

---

## WALKSNAIL ECOSYSTEM (COMPLETE)
- Walksnail Avatar Pro Kit (Air Unit Pro) ×1
- Walksnail Avatar HD Mini 1s Lite Kit ×1
- Walksnail Avatar HD Goggles X With Kit V2 ×1
- Walksnail Patch Antenna V2 for Goggles X ×1
- Goggles X Extension Board ×1

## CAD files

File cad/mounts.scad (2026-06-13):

// OpenSCAD Parametric Mounts for SBC FPV Integration
// Render with: openscad -o mount.stl mount.scad
// All dimensions in mm

// ============================================================
// GLOBAL PARAMETERS
// ============================================================
$fn = 60;  // Circle resolution

// Carbon fiber thickness
CF_THICK = 3.0;       // Typical 3mm carbon frame
CF_HOLE_DIA = 3.2;    // M3 clearance

// SBC mounting
M2_5_HOLE = 2.8;      // M2.5 clearance
M3_HOLE = 3.2;        // M3 clearance
STANDOFF_H = 10;      // Default standoff height

// ============================================================
// RADXA ROCK 5C LITE MOUNT
// ============================================================
module rock5c_mount(
    standoff_h = 12,
    include_heatsink = true,
    heatsink_w = 30,
    heatsink_l = 30,
    heatsink_h = 10,
    fan_mount = true,
    fan_size = 30,  // 3010 fan
    cable_relief = true,
    orientation = "flat"  // "flat" or "vertical"
) {
    // Rock 5C Lite PCB: 86 x 56 mm (verified from Radxa wiki)
    pcb_w = 86;
    pcb_l = 56;
    pcb_thick = 1.6;
    
    // Mounting holes (4x — from DXF at dl.radxa.com)
    // Exact positions not in public documentation — estimate from DXF
    mh_x = pcb_w - 10;   // ~76mm spacing
    mh_y = pcb_l - 10;   // ~46mm spacing
    
    difference() {
        union() {
            // Base plate with rounded corners
            translate([-pcb_w/2, -pcb_l/2, 0])
            rounded_box(pcb_w + 10, pcb_l + 10, standoff_h, 5);
            
            // Standoffs at mounting holes
            for (x = [-mh_x/2, mh_x/2], y = [-mh_y/2, mh_y/2]) {
                translate([x, y, 0])
                cylinder(d = 6, h = standoff_h);
            }
            
            // Heatsink mount
            if (include_heatsink) {
                translate([0, 0, standoff_h + pcb_thick])
                heatsink_block(heatsink_w, heatsink_l, heatsink_h, fan_mount, fan_size);
            }
            
            // Cable relief slots
            if (cable_relief) {
                translate([0, -pcb_l/2 - 5, standoff_h/2])
                rotate([90, 0, 0])
                cylinder(d = 12, h = 10);
            }
        }
        
        // Mounting holes (M2.5 clearance)
        for (x = [-mh_x/2, mh_x/2], y = [-mh_y/2, mh_y/2]) {
            translate([x, y, -1])
            cylinder(d = M2_5_HOLE, h = standoff_h + 2);
        }
        
        // PCB clearance (board sits on standoffs)
        translate([-pcb_w/2, -pcb_l/2, standoff_h])
        cube([pcb_w, pcb_l, pcb_thick + 0.5]);
        
        // Heatsink clearance
        if (include_heatsink) {
            translate([-heatsink_w/2, -heatsink_l/2, standoff_h + pcb_thick])
            cube([heatsink_w, heatsink_l, heatsink_h + 0.5]);
        }
    }
}

module heatsink_block(w, l, h, fan_mount, fan_size) {
    difference() {
        // Heatsink base
        translate([-w/2, -l/2, 0])
        cube([w, l, h]);
        
        // Fan mount cutout
        if (fan_mount) {
            translate([0, 0, h/2])
            cylinder(d = fan_size + 2, h = h + 1);
            
            // Fan screw holes (3010: 28mm pattern)
            fs = 28;
            for (x = [-fs/2, fs/2], y = [-fs/2, fs/2]) {
                translate([x, y, -1])
                cylinder(d = 3.2, h = h + 2);
            }
        }
        
        // Fin pattern (cosmetic - for airflow simulation)
        // Real fins would be printed separately or use off-the-shelf
    }
}

// ============================================================
// RADXA ZERO 3W MOUNT
// ============================================================
module zero3w_mount(
    standoff_h = 8,
    include_header = true,
    header_h = 8.5,
    orientation = "flat"
) {
    // Zero 3W PCB: 65 x 30 mm (verified from Radxa DXF)
    pcb_w = 65;
    pcb_l = 30;
    pcb_thick = 1.2;
    
    // Mounting holes: from DXF — 4x M2.5 at corners
    // Verified positions: (3.60,26.45), (61.40,3.60), (61.40,26.50), (3.55,3.60)
    // Approximate spacing for parametric model
    mh_spacing_x = 57.80;  // 61.40 - 3.60
    mh_spacing_y = 22.90;  // 26.50 - 3.60
    
    // 40-pin header position (centered)
    header_w = 52;  // 2.54mm × 20 pins
    header_l = 8.5;
    
    difference() {
        union() {
            // Base plate
            translate([-pcb_w/2 - 5, -pcb_l/2 - 5, 0])
            rounded_box(pcb_w + 10, pcb_l + 10, standoff_h, 4);
            
            // Standoffs at 4 corners
            for (x = [-mh_spacing/2, mh_spacing/2], y = [-mh_spacing/2, mh_spacing/2]) {
                translate([x, y, 0])
                cylinder(d = 5, h = standoff_h);
            }
            
            // 40-pin header relief
            if (include_header) {
                translate([-header_w/2, -header_l/2, standoff_h + pcb_thick])
                cube([header_w, header_l, header_h]);
            }
        }
        
        // Mounting holes (M2.5)
        for (x = [-mh_spacing/2, mh_spacing/2], y = [-mh_spacing/2, mh_spacing/2]) {
            translate([x, y, -1])
            cylinder(d = M2_5_HOLE, h = standoff_h + 2);
        }
        
        // PCB clearance
        translate([-pcb_w/2, -pcb_l/2, standoff_h])
        cube([pcb_w, pcb_l, pcb_thick + 0.3]);
        
        // Header clearance
        if (include_header) {
            translate([-header_w/2, -header_l/2, standoff_h + pcb_thick])
            cube([header_w, header_l, header_h + 1]);
        }
    }
}

// ============================================================
// KHADAS VIM4 MOUNT
// ============================================================
module vim4_mount(
    standoff_h = 10,
    include_cooler = true,
    cooler_w = 60,
    cooler_l = 60,
    cooler_h = 25,
    nvme_slot = true,
    orientation = "flat"
) {
    // VIM4 PCB: 82 x 58 mm (verified from Khadas docs)
    pcb_w = 82;
    pcb_l = 58;
    pcb_thick = 1.6;
    
    // Mounting holes: 4x M3 pattern
    // Estimated from PCB dimensions (exact positions not published)
    mh_x = 70;
    mh_y = 46;
    
    difference() {
        union() {
            // Base plate
            translate([-pcb_w/2 - 8, -pcb_l/2 - 8, 0])
            rounded_box(pcb_w + 16, pcb_l + 16, standoff_h, 6);
            
            // Standoffs
            for (x = [-mh_x/2, mh_x/2], y = [-mh_y/2, mh_y/2]) {
                translate([x, y, 0])
                cylinder(d = 7, h = standoff_h);
            }
            
            // Official active cooler mount
            if (include_cooler) {
                translate([0, 0, standoff_h + pcb_thick])
                cooler_block(cooler_w, cooler_l, cooler_h);
            }
            
            // NVMe slot access
            if (nvme_slot) {
                // M.2 2280 at bottom edge
                translate([0, -pcb_l/2 - 2, standoff_h/2])
                cube([25, 10, standoff_h]);
            }
            
            // HDMI IN/OUT port relief
            translate([-pcb_w/2 - 8, 0, standoff_h/2])
            cube([10, 20, standoff_h]);
        }
        
        // Mounting holes (M3)
        for (x = [-mh_x/2, mh_x/2], y = [-mh_y/2, mh_y/2]) {
            translate([x, y, -1])
            cylinder(d = M3_HOLE, h = standoff_h + 2);
        }
        
        // PCB clearance
        translate([-pcb_w/2, -pcb_l/2, standoff_h])
        cube([pcb_w, pcb_l, pcb_thick + 0.5]);
        
        // Cooler clearance
        if (include_cooler) {
            translate([-cooler_w/2, -cooler_l/2, standoff_h + pcb_thick])
            cube([cooler_w, cooler_l, cooler_h + 1]);
        }
    }
}

module cooler_block(w, l, h) {
    difference() {
        translate([-w/2, -l/2, 0])
        cube([w, l, h]);
        
        // Fan cutout (40x40mm typical)
        translate([0, 0, h/2])
        cylinder(d = 42, h = h + 1);
        
        // Fan screw holes
        fs = 32;
        for (x = [-fs/2, fs/2], y = [-fs/2, fs/2]) {
            translate([x, y, -1])
            cylinder(d = 3.2, h = h + 2);
        }
    }
}
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

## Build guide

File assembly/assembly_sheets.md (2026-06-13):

# FPV Fleet Assembly Sheets
**Generated:** 2025-12-12

---

## BUILD 1: 5" ANALOG FREESTYLE — Mark5 HD Frame
**FC:** Radiolink F405 / SpeedyBee F405 Mini Stack
**ESC:** Radiolink FLYCOLOR 55A 4in1
**Motors:** Axisflying 2207 1850KV ×4
**Props:** HQProp Ethix S5 5x4x3
**VTX:** AKK A1918 200-1000mW
**Cam:** Foxeer Razer Mini V3
**RX:** BETAFPV SuperD Diversity / RadioMaster RP3
**SBC:** Rock 5C Lite #1
**Battery:** OVONIC 6S 1300mAh / HRB 6S 1800mAh

### PARTS CHECKLIST
- [ ] Mark5 HD frame (carbon — **need to order Source One V5**)
- [ ] Radiolink F405 FC
- [ ] Radiolink FLYCOLOR 55A 4in1 ESC
- [ ] Axisflying 2207 1850KV motors ×4
- [ ] HQProp Ethix S5 5x4x3 props (8 CW, 8 CCW)
- [ ] AKK A1918 VTX + SMA antenna (RHCP)
- [ ] Foxeer Razer Mini V3 camera
- [ ] BETAFPV SuperD ELRS Diversity RX
- [ ] Rock 5C Lite #1 + mount + heatsink + fan + NVMe
- [ ] 5V 5A BEC (Pololu D24V50F5)
- [ ] M3×8mm standoffs ×4 (FC stack)
- [ ] M3×12mm standoffs ×4 (Rock 5C mount)
- [ ] M3×6mm screws ×16
- [ ] M3 nylon nuts ×8
- [ ] M5×6mm motor screws ×16 + M5 locknuts ×16
- [ ] XT60 pigtail (male)
- [ ] 22 AWG silicone wire (red/black) 200mm
- [ ] 26 AWG silicone wire (assorted) 300mm
- [ ] JST-GH 1.25mm connectors + pins
- [ ] Heat shrink 2mm/4mm/6mm
- [ ] 3M double-sided tape (for RX/VTX)
- [ ] Battery strap ×2
- [ ] Prop tool

### ASSEMBLY SEQUENCE

#### Step 1: Frame Prep (10 min)
1. Unpack frame, verify all carbon parts present
2. Clean edges with IPA if needed
3. Install M3×8mm standoffs at 30.5mm pattern (bottom plate)
4. Install M3×12mm standoffs at Rock 5C mount positions (top plate)

#### Step 2: Motor Mount (15 min)
1. Mount motors to arms: M5×6mm screws + locknuts
2. Torque: 1.5 Nm (hand tight + 1/4 turn)
3. Verify motor rotation: CW/CCW alternating
4. Route motor wires through arm channels

#### Step 3: ESC Install (10 min)
1. Place 4in1 ESC on FC standoffs (bottom of stack)
2. Connect motor wires to ESC pads (M1-M4)
3. Solder or plug: verify pinout matches motor order
4. Add capacitor (included) to ESC VBAT/GND

#### Step 4: FC Install (10 min)
1. Mount FC on standoffs above ESC (M3×8mm)
3. Connect ESC signal wires to FC M1-M4
4. Solder XT60 pigtail to FC VBAT/GND pads
5. Solder 5V BEC to FC 5V/GND (or use FC 5V out if 3A+)

#### Step 5: Rock 5C Mount (15 min)
1. Assemble Rock 5C mount: standoffs + heatsink + fan
2. Install NVMe SSD in PCIe slot
3. Mount Rock 5C on top plate standoffs
4. Connect 5V BEC → Rock 5C pins 2,4,6,9,14,20,25,30,34,39
5. Connect UART: Rock 5C Pin 8 → FC UART2_RX, Pin 10 → FC UART2_TX, Pin 9 → FC GND

#### Step 6: VTX & Camera (10 min)
1. Mount camera on front plate (adjustable angle)
2. Mount VTX on rear/top plate (3M tape + zip tie)
3. Connect camera → VTX CAM_IN
4. Connect VTX SmartAudio → FC UART4 (TX4/RX4)
5. Connect VTX power → FC 5V/GND (or BEC direct)

#### Step 7: RX Install (5 min)
1. Mount SuperD Diversity on top plate (3M tape)
2. Route antennas: one vertical, one horizontal
3. Connect RX → FC UART5 (CRSF): TX5→RX, RX5→TX, 5V, GND

#### Step 8: GPS & Extras (10 min)
1. Mount GPS (Matek M10Q-5883) on GPS mast
2. Connect GPS → FC UART3
3. Mount LED strip on rear arm
4. Connect LED → FC LED_STRIP
5. Mount beeper → FC BUZZER

#### Step 9: Wiring & Dress (15 min)
1. Route all wires in channels
2. Secure with zip ties every 50mm
3. Verify no wire touches props/carbon edges
4. Add heat shrink to all solder joints

#### Step 10: Pre-Flight Checks (10 min)
1. [ ] Continuity: BEC 5V → Rock 5C, BEC GND → Rock 5C
2. [ ] Continuity: Rock 5C UART ↔ FC UART2
3. [ ] Continuity: GPS → FC UART3
4. [ ] Continuity: VTX SmartAudio → FC UART4
5. [ ] Continuity: RX → FC UART5
6. [ ] Continuity: ESC signals → FC M1-M4
7. [ ] Battery voltage at FC VBAT pad
8. [ ] Smoke stopper test
9. [ ] Betaflight Configurator: verify all sensors, ports, motors
10. [ ] Motor direction test (props OFF)
11. [ ] SBC boot test (SSH to Rock 5C)
12. [ ] MSP telemetry flowing (Configurator CLI: `status`)

### TORQUE SPECS
| Fastener | Torque | Notes |
|---|---|---|
| M3 standoffs | 0.5 Nm | Hand tight + 1/8 turn |
| M5 motor screws | 1.5 Nm | Hand tight + 1/4 turn |
| M3 stack screws | 0.5 Nm | Nylon nuts — don't overtorque |
| Camera screws | 0.3 Nm | Tiny — just snug |

---

## BUILD 2: 3" ANALOG FREESTYLE — GX140 Frame
**FC:** SpeedyBee F405 Mini Stack (35A 4in1)
**ESC:** Integrated 35A 4in1 BLS
**Motors:** HGLRC Specter 1804 3500KV ×4
**Props:** GEMFAN 3052 3in
**VTX:** HGLRC Zeus 350mW
**Cam:** Caddx Ant 1200TVL
**RX:** SuperD Diversity / RP3 ELRS
**SBC:** Radxa Zero 3W
**Battery:** BETAFPV 2S 550mAh LiHV / OVONIC 2S 850mAh

### PARTS CHECKLIST
- [ ] GX140 140mm frame
- [ ] SpeedyBee F405 Mini Stack
- [ ] HGLRC Specter 1804 3500KV ×4
- [ ] GEMFAN 3052 props
- [ ] HGLRC Zeus 350mW VTX
- [ ] Caddx Ant camera
- [ ] SuperD Diversity / RP3 ELRS
- [ ] Radxa Zero 3W + 40-pin header soldered + mount
- [ ] M2.5×8mm standoffs ×4 (FC)
- [ ] M2.5×8mm standoffs ×4 (Zero 3W)
- [ ] M2.5×6mm screws ×16
- [ ] M2.5 nylon nuts ×8
- [ ] M3×5mm motor screws ×16 (1804 uses M3)
- [ ] XT30 pigtail
- [ ] 22/26 AWG wire
- [ ] JST-GH connectors
- [ ] Optical flow PAA5100 (optional)

### ASSEMBLY SEQUENCE
1. **Frame prep:** Install 20×20 standoffs
2. **Motors:** M3×5mm to arms, verify CW/CCW
3. **Stack:** Place 4in1 ESC bottom, FC top (20×20 pattern)
4. **Zero 3W:** Solder 40-pin header first, mount above FC
5. **VTX/Cam:** Front camera, rear VTX
6. **RX:** Top plate, antennas vertical/horizontal
7. **GPS:** On mast (optional for 3")
8. **Wiring:** FC 5V BEC → Zero 3W pins 2,4,6; UART2 cross-connect; I2C to optical flow
9. **Smoke test → Configurator → Motor test → SBC test**

### SPECIAL NOTES
- Zero 3W **no GPIO header** — must solder 40-pin header first
- SpeedyBee Mini 5V BEC only 3A — Zero 3W draws ~0.6A, OK
- 20×20 stack height tight — keep wires flat
- 3" props close to frame — verify Zero 3W mount clears

---

## BUILD 3: 2-2.5" WHOOP — Mobula8 (×2 Complete)
**Status:** RTF — Bind and fly
**FC:** Built-in X12 AIO (40A 4in1)
**Motors:** EX1103 11000KV
**VTX/Cam:** Built-in
**RX:** Built-in ELRS V3
**Battery:** BETAFPV 2S 550mAh LiHV

### PRE-FLIGHT
- [ ] Bind to RadioMaster Pocket / Boxer Crush
- [ ] Verify motor directions in Configurator
- [ ] Set failsafe (GPS Rescue not applicable)
- [ ] Check prop direction (all CCW on whoop? — verify)

---

## BUILD 4: 7" LONG RANGE — FPVDrone 295mm
**Status:** PENDING FC DECISION
**Options:**
- A) Matek H743-WLITE + Readytosky 40A singles ×4 + Rock 5C #2
- B) MicoAir H743V2 AIO (45A 4in1 built-in) + Rock 5C #2
- C) MicoAir H743 AIO alone (no SBC)

### PARTS NEEDED
- [ ] Frame (have)
- [ ] FC + ESC per decision above
- [ ] NEEBRC 2807 1300KV ×8 (have)
- [ ] HQProp 7x3.5x3 ×8 (have)
- [ ] GPS ×2 (Matek M10Q-5883 + FPVDrone M8N) (have)
- [ ] VTX: AKK A1918 / HGLRC Zeus (have)
- [ ] Cam: RunCam Racer Nano 4 (have)
- [ ] RX: SuperD Diversity + RP1 backup (have)
- [ ] Rock 5C #2 + mount + heatsink + NVMe (need mount parts)
- [ ] 5V 5A BEC ×2 (need)
- [ ] 4S/6S batteries (have HRB 4S + OVONIC 4S)

### DECISION MATRIX
| Factor | Matek H743 + Singles | MicoAir AIO | MicoAir Only |
|---|---|---|---|
| Mounting | **25×25 M2** (needs adapter) | 30.5×30.5 / **25.5×25.5 AIO-45A** | 25.5×25.5 |
| Redundancy | ESC separate | All-in-one | All-in-one |
| SBC support | Rock 5C UART | Rock 5C UART | None |
| Weight | Higher | Lower | Lowest |
| Current capability | 40A×4 = 160A | 45A×4 = 180A | 45A×4 |
| Complexity | Medium | Low | Lowest |
| **Recommendation** | **Option A** — best for SBC + redundancy |

---

## BUILD 5: 450MM PLATFORM — YoungRC / HAWK'S WORK
**FC:** Matek H743-WLITE + PDB-HEX OR GoolRC F722
**ESC:** Readytosky 40A singles ×4
**Motors:** Readytosky 2212 920KV ×4
**Props:** 10x4.5 ×12
**VTX:** AKK A1918
**Cam:** Readytosky 1200TVL
**RX:** ELRS (RP3)
**Battery:** HRB 4S 4000/5000mAh

### STATUS
- Frame: Have both
- FC: Have both (choose one)
- ESC: Have singles
- Motors: Have
- Props: Have
- VTX/Cam: Have
- RX: Have
- **Ready to assemble** — pick FC, wire per 5" but 4S

---

## BUILD 6: MARIO 5 O4 — DJI O4 CINEMATIC
**Frame:** Mario 5 O4 XH 226mm
**VTX/Cam:** **NEED DJI O4 PRO AIR UNIT**
**FC:** GoolRC F722 / SoloGood F722 Stack
**ESC:** SoloGood 60A BLS8
**Motors:** Axisflying 2207 1850KV
**RX:** SuperD Diversity
**Battery:** OVONIC 6S 1300mAh

### BLOCKER
**DJI O4 Pro Air Unit — $150 — MUST ORDER**

---

## UNIVERSAL PRE-FLIGHT CHECKLIST (ALL BUILDS)

### Electrical
- [ ] Smoke stopper test (no light = pass)
- [ ] Continuity: all power rails (5V, 3.3V, GND)
- [ ] Continuity: all signal wires (UART, I2C, SPI, PWM)
- [ ] No shorts between adjacent pins
- [ ] Battery leads: correct polarity at FC/ESC

### Mechanical
- [ ] All screws torqued to spec
- [ ] No loose wires near props
- [ ] Antennas secured, not touching carbon
- [ ] Camera angle set (verify in Configurator)
- [ ] Battery strap holds pack firmly
- [ ] Props correct orientation (CW/CCW)

### Software (Betaflight Configurator)
- [ ] Firmware current (2025.12)
- [ ] Ports: MSP, GPS, VTX, RX, SBC UART all assigned
- [ ] Sensor: Gyro/Accel calibrated
- [ ] Motor direction: all correct
- [ ] Motor protocol: DShot600
- [ ] RPM filter: ON (if bidirectional DShot)
- [ ] Dynamic notch: ON
- [ ] ESC telemetry: ON
- [ ] OSD: elements positioned
- [ ] Failsafe: stage 1/2 configured
- [ ] GPS Rescue: tuned (if GPS)
- [ ] SBC MSP: telemetry flowing (`status` in CLI)

### SBC Specific
- [ ] OS booted (SSH accessible)
- [ ] RKNPU2 / NN SDK loaded
- [ ] Model inference test passes
- [ ] MSP bridge running (Rock 5C) / Telemetry bridge (Zero 3W)
- [ ] NVMe mounted (Rock 5C)
- [ ] Temps under load < 70°C

### Field Test
- [ ] Hover test 30s — no vibrations
- [ ] Punch-out — no oscillations
- [ ] Roll/Flip — clean stops, no bounce
- [ ] GPS lock < 60s (if equipped)
- [ ] RTH test (if GPS Rescue)
- [ ] SBC telemetry logging
- [ ] Post-flight: motor temps < 50°C, SBC temps < 65°C

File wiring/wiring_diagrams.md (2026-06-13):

# FPV Fleet Wiring Diagrams & Pinout Tables
**Generated:** 2025-12-12
**Format:** Text tables for KiCad netlist import / manual wiring

---

## 1. ROCK 5C → FC UART (MSP/MAVLink) — Primary Telemetry

### Rock 5C GPIO (40-pin Header) — J2

All GPIOs 3.3V logic (max 3.63V). Source: [Radxa Rock 5C Hardware Interface](https://docs.radxa.com/en/rock5/rock5c/hardware-design/hardware-interface)

| Pin | Name | GPIO# | Alt Function | FC Connection | Wire | Notes |
|-----|---|---|---|---|---|---|
| 1 | 3.3V | — | Power | — | — | Do not connect to FC |
| 2 | 5V | — | Power in | **BEC 5V out** | 22 AWG red | **Main power input** |
| 3 | GPIO1_D7 | 63 | UART1_CTSN_M1, I2C8_SDA_M2 | — | — | Free |
| 4 | 5V | — | Power in | **BEC 5V out** | 22 AWG red | Parallel |
| 5 | GPIO1_D6 | 62 | UART1_RTSN_M1, I2C8_SCL_M2 | — | — | Free |
| 6 | GND | — | Ground | **BEC GND** / FC GND | 22 AWG black | **Main ground** |
| 7 | GPIO1_B3 | 43 | UART4_TX_M2 | — | — | Free |
| 8 | **GPIO0_B5** | **13** | **UART2_TX_M0**, I2C1_SCL_M0 | **FC UART_RX (TELEM2)** | 26 AWG | **MSP TX → FC RX** |
| 9 | GND | — | Ground | FC GND | 26 AWG black | Signal ground |
| 10 | **GPIO0_B6** | **14** | **UART2_RX_M0**, I2C1_SDA_M0 | **FC UART_TX (TELEM2)** | 26 AWG | **MSP RX ← FC TX** |
| 11 | GPIO4_B3 | 139 | UART8_CTSN_M0 | — | — | Free |
| 12 | GPIO4_B2 | 138 | UART8_RTSN_M0, SPI0_CS0_M1 | — | — | Free |
| 13 | GPIO4_B4 | 140 | UART9_TX_M1, PWM11_IR_M1 | — | — | Free |
| 14 | GND | — | Ground | — | — | — |
| 15 | GPIO1_A1 | 33 | UART6_TX_M1, I2C2_SCL_M4 | — | — | Free |
| 16 | GPIO1_A0 | 32 | UART6_RX_M1, I2C2_SDA_M4 | — | — | Free |
| 17 | 3.3V | — | Power | — | — | Do not connect |
| 18 | GPIO1_A2 | 34 | UART6_RTSN_M1, I2C4_SDA_M3 | — | — | Free |
| 19 | GND | — | Ground | — | — | — |
| 20 | GPIO0_C7 | 23 | UART1_RTSN_M2, I2C6_SDA_M0 | — | — | Free (USB4 via R104) |
| 21 | GPIO1_B2 | 42 | UART4_RX_M2, SPI0_MOSI_M2 | — | — | Free |
| 22 | GPIO1_B1 | 41 | SPI0_MISO_M2 | — | — | Free |
| 23 | GPIO1_B4 | 44 | UART7_RX_M2, SPI0_CS0_M2 | — | — | Free |
| 24 | GPIO4_A0 | 128 | UART9_RTSN_M1, I2S1_MCLK_M0 | — | — | Free |
| 25 | GND | — | Ground | — | — | — |
| 26 | GPIO1_A5 | 37 | SPI2_MOSI_M0 | — | — | Free |
| 27 | GPIO1_B0 | 40 | SPI2_CS1_M0 | — | — | Free |
| 28 | GND | — | Ground | — | — | — |
| 29 | GPIO1_B5 | 45 | UART7_TX_M2 | — | — | Free |
| 30 | GPIO1_A3 | 35 | PWM1_M2 | — | — | Free |
| 31 | GPIO1_A4 | 36 | SPI2_MISO_M0 | — | — | Free |
| 32 | GPIO0_D0 | 24 | UART1_CTSN_M2, SPI3_MISO_M2 | — | — | Free (USB4 via R106) |
| 33 | GND | — | Ground | — | — | — |
| 34 | GPIO4_B0 | 136 | UART8_TX_M0, I2C6_SDA_M3 | — | — | Free |
| 35 | GND | — | Ground | — | — | — |
| 36 | GPIO4_A2 | 130 | SPI0_CLK_M1, I2S1_LRCK_M0 | — | — | Free |
| 37 | GPIO4_A5 | 133 | UART3_TX_M2, I2C3_SDA_M2 | — | — | Free |
| 38 | GPIO4_A1 | 129 | SPI0_MOSI_M1, I2S1_SCLK_M0 | — | — | Free |
| 39 | GND | — | Ground | — | — | — |
| 40 | GPIO4_B1 | 137 | UART8_RX_M0, I2C6_SCL_M3, SPI0_CS1_M1 | — | — | Free |

### Critical Connections (Minimum Viable)
| Rock 5C | GPIO# | Wire | FC (TELEM2) | Protocol |
|---|---|---|---|---|
| Pin 2 (5V) | — | 22 AWG red | BEC 5V | Power |
| Pin 6 (GND) | — | 22 AWG black | BEC GND | Power |
| Pin 8 (UART2_TX) | **GPIO 13** | 26 AWG | FC UART_RX | MSP/MAVLink |
| Pin 10 (UART2_RX) | **GPIO 14** | 26 AWG | FC UART_TX | MSP/MAVLink |
| Pin 9 (GND) | — | 26 AWG black | FC GND | Signal ref |

### Baude Rate Config
- **MSP:** 115200 / 921600 (Betaflight Configurator → Ports → TELEM2 → MSP)
- **MAVLink:** 57600 / 115200 (ArduPilot / INAV)

---

## 2. RADXA ZERO 3W → FC (Lightweight Bridge)

### Zero 3W GPIO (40-pin Header) — J2

All GPIOs 3.3V logic. Source: [Radxa Zero 3W Hardware Interface](https://docs.radxa.com/en/zero/zero3/hardware-design/hardware-interface)

| Pin | Name | GPIO# | Alt Function | FC Connection | Wire | Notes |
|-----|---|---|---|---|---|---|
| 1 | 3.3V | — | Power | — | — | Max 500mA |
| 2 | 5V | — | **Power in** | **FC 5V BEC** | 22 AWG red | **Main power** |
| 3 | GPIO1_A0 | 32 | UART3_RX_M0, I2C3_SCL_M0 | — | — | Free (alt UART) |
| 4 | 5V | — | **Power in** | **FC 5V BEC** | 22 AWG red | Parallel |
| 5 | GPIO1_A1 | 33 | UART3_TX_M0, I2C3_SDA_M0 | — | — | Free (alt UART) |
| 6 | GND | — | **Ground** | **FC GND** | 22 AWG black | **Main ground** |
| 7 | PWM14_M0 | 116 | PWM | — | — | Free |
| 8 | **GPIO0_D1** | **25** | **UART2_TX_M0** | **FC UART_RX (TELEM1)** | 26 AWG | **MSP TX → FC RX** |
| 9 | GND | — | Ground | FC GND | 26 AWG black | Signal ref |
| 10 | **GPIO0_D0** | **24** | **UART2_RX_M0** | **FC UART_TX (TELEM1)** | 26 AWG | **MSP RX ← FC TX** |
| 11 | GPIO3_A1 | 97 | Free | — | — | Free |
| 12 | GPIO3_A2 | 98 | I2S3_MCLK_M0 | — | — | Free |
| 13 | GPIO3_B0 | 104 | Free | — | — | Free |
| 14 | GND | — | Ground | — | — | — |
| 15 | GPIO4_C3 | 147 | SPI3_MOSI_M1 | — | — | Free |
| 16 | GPIO3_B1 | 105 | UART4_RX_M1 | FC LED | 26 AWG | Status LED |
| 17 | 3.3V | — | Power | — | — | Max 500mA |
| 18 | GPIO3_B2 | 106 | UART4_TX_M1 | FC BUZZER | 26 AWG | Beeper trigger |
| 19 | GPIO4_C5 | 149 | SPI3_MISO_M1 | — | — | Free |
| 20 | GND | — | Ground | — | — | — |
| 21 | GPIO4_C2 | 146 | SPI3_CLK_M1 | — | — | Free |
| 22 | GPIO3_C1 | 113 | I2S1_SDO2_M2 | — | — | Free |
| 23 | GPIO4_C6 | 150 | SPI3_CS0_M1 | — | — | Free |
| 24 | NC | — | Not connected | — | — | — |
| 25 | GND | — | Ground | — | — | — |
| 26 | GPIO4_B2 | 138 | I2C4_SDA_M0 | — | — | Free (USB2 alt) |
| 27 | GPIO3_B3 | **107** | **I2C5_SCL_M0** | **FC I2C1 SCL** | 28 AWG | **Optical flow clock** |
| 28 | GPIO4_B3 | 139 | I2C4_SCL_M0 | — | — | Free (USB2 alt) |
| 29 | GND | — | Ground | — | — | — |
| 30 | GPIO3_C2 | 114 | UART5_TX_M1 | — | — | Free |
| 31 | GPIO3_B4 | **108** | **I2C5_SDA_M0** | **FC I2C1 SDA** | 28 AWG | **Optical flow data** |
| 32 | GND | — | Ground | — | — | — |
| 33 | GPIO3_A7 | 103 | Free | — | — | Free |
| 34 | GPIO3_A6 | 102 | I2S3_SDI_M0 | — | — | Free |
| 35 | GPIO3_A5 | 101 | I2S3_SDO_M0 | — | — | Free |
| 36 | GPIO3_C3 | 115 | UART5_RX_M1 | — | — | Free |
| 37 | GPIO1_A4 | 36 | I2S1_SCLK_RX_M0 | — | — | Free |
| 38 | GND | — | Ground | — | — | — |
| 39 | 3.3V | — | Power | — | — | Max 500mA |
| 40 | NC | — | Not connected | — | — | — |

### Critical Connections (Zero 3W)
| Zero 3W | GPIO# | Wire | FC | Purpose |
|---|---|---|-----|---|
| Pin 2 (5V) | — | 22 AWG red | 5V BEC | Power |
| Pin 6 (GND) | — | 22 AWG black | GND | Power |
| Pin 8 (UART2_TX) | **GPIO 25** | 26 AWG | UART_RX (TELEM1) | MSP TX → FC RX |
| Pin 10 (UART2_RX) | **GPIO 24** | 26 AWG | UART_TX (TELEM1) | MSP RX ← FC TX |
| Pin 29 (I2C5_SCL) | **GPIO 107** | 28 AWG | I2C1 SCL | Optical flow clock |
| Pin 31 (I2C5_SDA) | **GPIO 108** | 28 AWG | I2C1 SDA | Optical flow data |
| Pin 9 (GND) | — | 26 AWG black | GND | Signal ref |

---

## 3. KHADAS VIM4 — Ground Station HDMI Capture

### VIM4 Ports (No GPIO wiring needed for primary function)
| Port | Connection | Cable | Notes |
|---|---|---|---|
| HDMI IN | **Walksnail Goggles X HDMI OUT** | HDMI 2.0 cable 2m | 4K@60 capture |
| HDMI OUT | Monitor / HDMI splitter | HDMI cable | Passthrough |
| USB3 | NVMe enclosure / Coral M.2 | USB3 cable | Storage / +4 TOPS |
| GbE | LAN / GCS tether | Cat6 | 1Gbps |
| 12V Barrel | 12V 2A supply | Barrel jack | Center positive |
| WiFi 6 | Router / Phone hotspot | — | Wireless stream |
| BT 5.1 | Gamepad / Phone | — | Control |

### Optional GPIO (40-pin) — Expansion
| Pin | Function | Use Case |
|-----|---|---|
| 3/5 | I2C | External sensors |
| 8/10 | UART | Secondary telemetry |
| 12 | PWM | Fan control |
| 16 | GPIO | Record trigger button |

---

## 4. FC STANDARD PORT MAPPINGS (Betaflight)

### Typical 30.5×30.5 FC (Radiolink F405, SpeedyBee F405, Matek H743)
| Port | Pins | Default Function | Our Use |
|---|---|---|---|
| **USB** | USB-C | Configurator / MSP | Ground config |
| **UART1** | TX1/RX1 | MSP (USB fallback) | — |
| **UART2** | TX2/RX2 | **TELEM2** | **Rock 5C MSP** |
| **UART3** | TX3/RX3 | GPS | GPS module |
| **UART4** | TX4/RX4 | VTX (SmartAudio) | VTX control |
| **UART5** | TX5/RX5 | RX (CRSF/ELRS) | ELRS receiver |
| **UART6** | TX6/RX6 | — | Zero 3W MSP (if available) |
| **I2C1** | SDA/SCL | Baro/Compass | Zero 3W optical flow |
| **I2C2** | SDA/SCL | — | Free |
| **SPI1** | SCK/MISO/MOSI/CS | Gyro/OSD | Internal |
| **SPI2** | SCK/MISO/MOSI/CS | SD Card | Blackbox |
| **CAN** | CANH/CANL | — | Future (DroneCAN) |
| **ADC** | Vbat/Ibat | Battery monitor | Internal |
| **PWM** | M1-M8 | Motors/ESC | DShot600 |
| **LED** | LED_STRIP | WS2812 | Status |
| **BUZZER** | BZ+/BZ- | Beeper | Beeper |
| **CAM** | CAM_CTRL | Camera control | Optional |

### 20×20 FC (SpeedyBee F405 Mini, GoolRC F722)
| Port | Pins | Use |
|---|---|-----|
| UART1 | TX1/RX1 | USB/MSP |
| UART2 | TX2/RX2 | **Rock 5C / Zero 3W** |
| UART3 | TX3/RX3 | GPS |
| UART4 | TX4/RX4 | VTX / ELRS RX |
| I2C | SDA/SCL | Sensors / Optical flow |

---

## 5. BATTERY & POWER DISTRIBUTION

### 5" / 7" Build (6S LiPo)
```
LiPo 6S (22.2V)
    │
    ├─► XT60 → FC BAT pads (Vbat/Ibat sensing)
    │
    ├─► 5V 5A BEC (Pololu D24V50F5 / Matek 5V 5A)
    │       │
    │       ├─► 22 AWG → Rock 5C Pin 2/4 (5V)
    │       ├─► 22 AWG → Rock 5C Pin 6/9/14/20/25/30/34/39 (GND)
    │       ├─► 22 AWG → Zero 3W Pin 2/4 (5V)
    │       ├─► 22 AWG → Zero 3W Pin 6 (GND)
    │       ├─► Servo rail (if used)
    │       └─► LED strip (5V)
    │
    └─► ESC → Motors (DShot600)
```

### 3" Build (3-4S LiPo)
```
LiPo 4S (14.8V)
    │
    ├─► FC Vbat/Ibat
    │
    ├─► 5V 3A BEC (integrated in SpeedyBee F405 Mini)
    │       │
    │       ├─► 22 AWG → Zero 3W Pin 2/4 (5V)
    │       ├─► 22 AWG → Zero 3W Pin 6 (GND)
    │       └─► FC 5V rail
    │
    └─► ESC → Motors
```

### Goggle Battery (2S LiPo)
```
2S 7.4V → XT30 → Goggles / VTX / Camera
```

---

## 6. GROUND STATION WIRING (VIM4)

```
Walksnail Goggles X
    │
    HDMI OUT ──────────► HDMI IN (VIM4) ──► HDMI OUT ──► Monitor
    │
    USB-C ────────────► Power (2S LiPo via XT30)
    │
    UART ─────────────► ELRS Module (CRSF)

VIM4
    │
    HDMI IN ───────────► Capture pipeline
    HDMI OUT ──────────► HDMI splitter ──► Monitor + Recorder
    USB3 ──────────────► NVMe 512GB (recordings)
    USB3 ──────────────► Coral M.2 (optional +4 TOPS)
    GbE ───────────────► Router ──► Phone/PC (stream)
    12V ────────────────► 12V 2A Supply
```

---

## 7. WIRE GAUGE & LENGTH RECOMMENDATIONS

| Function | Gauge | Max Length | Color | Connector |
|---|---|---|---|---|
| Main 5V (BEC→SBC) | 22 AWG | 150mm | Red | JST-GH / bare |
| Main GND | 22 AWG | 150mm | Black | JST-GH / bare |
| Signal (UART/I2C) | 26-28 AWG | 200mm | Yellow/White | JST-GH / bare |
| ESC Signal | 26 AWG | 100mm | White | JST-SH / bare |
| Battery (XT60) | 14 AWG | 50mm | Red/Black | XT60 |
| Battery (XT30) | 18 AWG | 50mm | Red/Black | XT30 |
| LED Strip | 24 AWG | 300mm | Green | JST-SM |
| Beeper | 26 AWG | 100mm | Orange | JST-SH |

### Crimp Connectors Used
| Connector | Pitch | Use | Crimper |
|---|---|-----|---|
| JST-GH | 1.25mm | FC↔SBC, GPS, I2C | Engineer PA-09 |
| JST-SH | 1.0mm | ESC, Camera, LED | Engineer PA-09 |
| JST-SM | 2.5mm | Battery, High current | Engineer PA-20 |
| XT60 | — | 6S/4S Main | — |
| XT30 | — | 2S/3S, Goggles | — |
| BT2.0 | — | 1S Whoop | — |

---

## 8. KICAD NETLIST (S-Expression) — Import to Eeschema

```
(kicad_netlist
  (version 4)
  (tool "fpv_fleet_generator")
  (date "2025-12-12")
  (components
    (comp (ref "ROCK5C_1") (value "Radxa_Rock5C_Lite") (footprint "Package_DIP:DIP-40_W7.62mm") (libsource "fpv:SBC"))
    (comp (ref "ROCK5C_2") (value "Radxa_Rock5C_Lite") (footprint "Package_DIP:DIP-40_W7.62mm") (libsource "fpv:SBC"))
    (comp (ref "ZERO3W") (value "Radxa_Zero3W") (footprint "Package_DIP:DIP-40_W7.62mm") (libsource "fpv:SBC"))
    (comp (ref "VIM4") (value "Khadas_VIM4") (footprint "Package_DIP:DIP-40_W7.62mm") (libsource "fpv:SBC"))
    (comp (ref "FC_5INCH") (value "FC_F405_F722_H743") (footprint "Package_DIP:DIP-30_W7.62mm") (libsource "fpv:FC"))
    (comp (ref "FC_3INCH") (value "FC_F405_Mini") (footprint "Package_DIP:DIP-20_W7.62mm") (libsource "fpv:FC"))
    (comp (ref "BEC_5V5A") (value "Pololu_D24V50F5") (footprint "Package_TO_SOT:TO-220-3_Vertical") (libsource "fpv:Power"))
    (comp (ref "ESC_4IN1") (value "ESC_4in1_30A_60A") (footprint "fpv:ESC_4in1_30x30") (libsource "fpv:ESC"))
    (comp (ref "ESC_SINGLE") (value "ESC_Single_60A") (footprint "fpv:ESC_Single") (libsource "fpv:ESC"))
    (comp (ref "VOLTAGE") (value "LiPo_6S_22.2V") (footprint "Connector_XT60") (libsource "fpv:Battery"))
    (comp (ref "CAM_IMX219") (value "IMX219_Camera") (footprint "fpv:Camera_MIPI") (libsource "fpv:Camera"))
    (comp (ref "FLOW_PAA5100") (value "PAA5100_OpticalFlow") (footprint "fpv:Sensor_SPI") (libsource "fpv:Sensor"))
    (comp (ref "GPS_MATEK") (value "Matek_M10Q_5883") (footprint "fpv:GPS_M10") (libsource "fpv:GPS"))
  )
  (nets
    (net (code "1") (name "5V_SBC") (nodes (ref "BEC_5V5A" pin "VOUT") (ref "ROCK5C_1" pin "2") (ref "ROCK5C_1" pin "4") (ref "ROCK5C_2" pin "2") (ref "ROCK5C_2" pin "4") (ref "ZERO3W" pin "2") (ref "ZERO3W" pin "4")))
    (net (code "2") (name "GND") (nodes (ref "BEC_5V5A" pin "GND") (ref "ROCK5C_1" pin "6") (ref "ROCK5C_1" pin "9") (ref "ROCK5C_1" pin "14") (ref "ROCK5C_2" pin "6") (ref "ROCK5C_2" pin "9") (ref "ZERO3W" pin "6") (ref "FC_5INCH" pin "GND") (ref "FC_3INCH" pin "GND") (ref "ESC_4IN1" pin "GND") (ref "VOLTAGE" pin "GND")))
    (net (code "3") (name "UART_ROCK5C_MSP") (nodes (ref "ROCK5C_1" pin "8") (ref "FC_5INCH" pin "UART2_RX")))  // ROCK5C TX → FC RX
    (net (code "4") (name "UART_ROCK5C_MSP_RET") (nodes (ref "ROCK5C_1" pin "10") (ref "FC_5INCH" pin "UART2_TX")))  // FC TX → ROCK5C RX
    (net (code "5") (name "UART_ZERO3W_MSP") (nodes (ref "ZERO3W" pin "8") (ref "FC_3INCH" pin "UART2_RX")))  // ZERO3W TX → FC RX
    (net (code "6") (name "UART_ZERO3W_MSP_RET") (nodes (ref "ZERO3W" pin "10") (ref "FC_3INCH" pin "UART2_TX")))  // FC TX → ZERO3W RX
    (net (code "7") (name "I2C_FLOW") (nodes (ref "ZERO3W" pin "29") (ref "FLOW_PAA5100" pin "SDA") (ref "ZERO3W" pin "31") (ref "FLOW_PAA5100" pin "SCL")))  // I2C5_SCL_M0 (GPIO107), I2C5_SDA_M0 (GPIO108)
    (net (code "8") (name "UART_GPS") (nodes (ref "FC_5INCH" pin "UART3_TX") (ref "GPS_MATEK" pin "RX") (ref "FC_5INCH" pin "UART3_RX") (ref "GPS_MATEK" pin "TX")))
    (net (code "9") (name "UART_VTX") (nodes (ref "FC_5INCH" pin "UART4_TX") (ref "VTX" pin "RX") (ref "FC_5INCH" pin "UART4_RX") (ref "VTX" pin "TX")))
    (net (code "10") (name "UART_ELRS") (nodes (ref "FC_5INCH" pin "UART5_TX") (ref "ELRS_RX" pin "RX") (ref "FC_5INCH" pin "UART5_RX") (ref "ELRS_RX" pin "TX")))
    (net (code "11") (name "PWM_MOTORS") (nodes (ref "FC_5INCH" pin "M1") (ref "ESC_4IN1" pin "S1") ... (ref "FC_5INCH" pin "M8") (ref "ESC_4IN1" pin "S8")))
    (net (code "12") (name "VBAT") (nodes (ref "VOLTAGE" pin "VCC") (ref "FC_5INCH" pin "VBAT") (ref "ESC_4IN1" pin "VBAT")))
    (net (code "13") (name "IBAT") (nodes (ref "VOLTAGE" pin "GND") (ref "FC_5INCH" pin "IBAT") (ref "ESC_4IN1" pin "GND")))
    (net (code "14") (name "HDMI_VIM4_IN") (nodes (ref "GOGGLES_X" pin "HDMI_OUT") (ref "VIM4" pin "HDMI_IN")))
    (net (code "15") (name "HDMI_VIM4_OUT") (nodes (ref "VIM4" pin "HDMI_OUT") (ref "MONITOR" pin "HDMI_IN") (ref "RECORDER" pin "HDMI_IN")))
  )
)
```

---

## 9. ASSEMBLY WIRING CHECKLIST PER BUILD

### 5" Analog (Rock 5C #1)
- [ ] BEC 5V 5A → Rock 5C Pins 2,4,6,9,14,20,25,30,34,39
- [ ] Rock 5C Pin 8 (UART2_TX) → FC UART2_RX (TELEM2)
- [ ] Rock 5C Pin 10 (UART2_RX) → FC UART2_TX (TELEM2)
- [ ] Rock 5C Pin 9 (GND) → FC GND (signal ref)
- [ ] GPS → FC UART3
- [ ] VTX SmartAudio → FC UART4
- [ ] ELRS RX → FC UART5 (CRSF)
- [ ] ESC DShot → FC M1-M4
- [ ] LED Strip → FC LED_STRIP
- [ ] Beeper → FC BUZZER
- [ ] Battery XT60 → FC VBAT/IBAT + ESC
- [ ] Rock 5C NVMe installed
- [ ] Rock 5C heatsink + fan mounted
- [ ] All wires routed in channels, secured
- [ ] Smoke stopper test before first plug

### 3" Analog (Zero 3W)
- [ ] FC 5V BEC → Zero 3W Pins 2,4,6
- [ ] Zero 3W Pin 8 (UART2_TX) → FC UART2_RX (TELEM1)
- [ ] Zero 3W Pin 10 (UART2_RX) → FC UART2_TX (TELEM1)
- [ ] Zero 3W Pin 3,5 (I2C) → Optical Flow PAA5100
- [ ] GPS → FC UART3
- [ ] ELRS RX → FC UART4/5
- [ ] ESC DShot → FC M1-M4
- [ ] Battery → FC + ESC
- [ ] Zero 3W header soldered

### 7" Long Range (Rock 5C #2 or MicoAir H743 AIO)
- [ ] Decision: Rock 5C + Matek H743-WLITE OR MicoAir H743 AIO
- [ ] If Rock 5C: Same as 5" but GPS Rescue tuned
- [ ] If MicoAir: Built-in 45A 4in1, no separate ESC
- [ ] Crossfire/ELRS Diversity RX
- [ ] Dual GPS (Matek M10Q-5883 ×2)
- [ ] 8× NEEBRC 2807 motors
- [ ] 6S batteries

---

## 10. CONTINUITY TEST MATRIX (Post-Assembly)

| Test | Expected | Method |
|---|---|---|
| BEC 5V → Rock 5C Pin 2 | < 0.1Ω | Multimeter continuity |
| BEC GND → Rock 5C Pin 6 | < 0.1Ω | Multimeter continuity |
| Rock 5C Pin 8 → FC UART2_RX | < 0.5Ω | Multimeter continuity |
| Rock 5C Pin 10 → FC UART2_TX | < 0.5Ω | Multimeter continuity |
| FC UART2_TX → Rock 5C Pin 10 | Signal check | Oscilloscope / logic analyzer |
| GPS TX → FC UART3_RX | Signal check | Betaflight Configurator GPS tab |
| VTX SmartAudio → FC UART4 | Signal check | VTX tables in Configurator |
| ELRS RX → FC UART5 | Signal check | RSSI/LQ in OSD |
| ESC DShot → FC M1-M4 | Motor spin test | Configurator Motors tab |
| Battery voltage → FC VBAT | 22.2V ±0.1V | Multimeter |
| Current sensor → FC IBAT | 0A at rest | Configurator |
| Smoke stopper | No light | Visual |

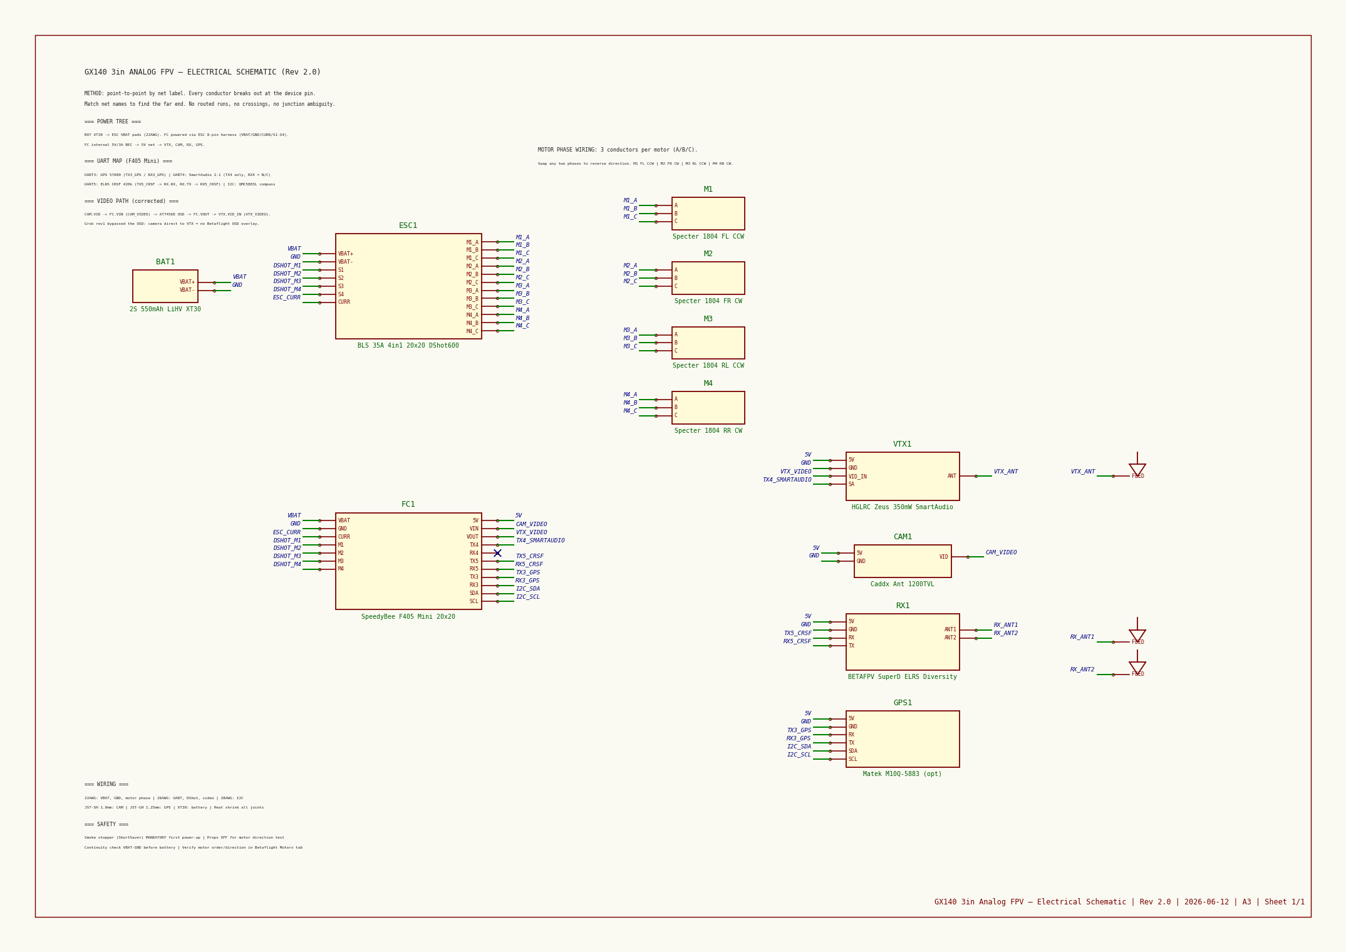
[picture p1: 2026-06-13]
builds/gx140/gx140_rev2_preview.png

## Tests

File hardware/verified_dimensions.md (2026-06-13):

# FPV Drone Fleet — Verified Component Dimensions

> Compiled: 2026-06-12  
> Sources: Manufacturer wikis, datasheets, CAD files, retailer listings  
> All measurements in mm (metric). NOT FOUND = unverifiable from public sources.

---

## Table of Contents

1. [RADXA ROCK 5C Lite (RK3588S2)](#1-radxa-rock-5c-lite-rk3588s2)
2. [RADXA Zero 3W (RK3566)](#2-radxa-zero-3w-rk3566)
3. [KHADAS VIM4 (A311D2)](#3-khadas-vim4-a311d2)
4. [Frames](#4-frames)
5. [Flight Controllers](#5-flight-controllers)
6. [ESCs](#6-escs)
7. [Motors](#7-motors)
8. [VTX / Cameras / Receivers](#8-vtx--cameras--receivers)
9. [Radios / Goggles / GPS](#9-radios--goggles--gps)

---

## 1. RADXA ROCK 5C Lite (RK3588S2)

| Property | Value | Source |
|---|---|---|
| PCB Dimensions (L×W) | 86 × 56 mm (bounding box) | [Radxa Wiki](https://docs.radxa.com/en/rock5/rock5c/getting-started/introduction) |
| PCB Thickness | NOT FOUND | |
| Overall Height (H) | NOT FOUND | |
| Weight | NOT FOUND — not in any datasheet | |
| Mounting Hole Dia | NOT FOUND — CAD files available at dl.radxa.com | [DXF](https://dl.radxa.com/rock5/5c/docs/hw/v1100/radxa_rock_5c_2d_dxf_v1100.zip) |
| Mounting Hole Positions | NOT FOUND — extractable from STEP/DXF | [STEP](https://dl.radxa.com/rock5/5c/docs/hw/dimension/5c_pcba.stp.zip) |
| Power Input | 5V DC via USB-C or GPIO pins 2/4 | [Product Brief](https://dl.radxa.com/rock5/5c/docs/hw/v1100/radxa_rock5c_product_brief.pdf) |
| Min PSU | 10W (2A) | Same |
| Full Load PSU | 25W (5A) — with USB 3.0 + PCIe | Same |
| USB Port Current | 2.8A aggregate across 4× USB-A | Same |
| Ambient Operating Temp | 0°C to 50°C | Same |
| SoC Throttle Temp | 80°C (internal) | Same |
| PCIe Connector | 16-pin FPC, 0.5mm pitch, PCIe 2.1 x1, top side near 40-pin header | [Schematic v1.1](https://dl.radxa.com/rock5/5c/docs/hw/v1100/radxa_rock_5c_schematic_v1100.pdf) |
| MIPI CSI | 1× 4-lane (splittable to 2× 2-lane), FPC connector | Same |

### ROCK 5C Lite — GPIO Pinout (40-pin, 2.54mm pitch)

All GPIOs 3.3V logic (max 3.63V). GPIO numbering: `GPIOX_Bn` = (X × 32) + (B × 8) + n (A=0, B=1, C=2, D=3).

Source: [Radxa Hardware Interface](https://docs.radxa.com/en/rock5/rock5c/hardware-design/hardware-interface)

**Left Side (odd pins 1–39):**

| Pin | GPIO# | GPIO Name | Alternate Functions |
|-----|---|---|---|
| 1 | — | +3.3V | Power |
| 3 | 63 | GPIO1_D7 | UART1_CTSN_M1, I2C8_SDA_M2, PWM15_IR_M3 |
| 5 | 62 | GPIO1_D6 | UART1_RTSN_M1, I2C8_SCL_M2, PWM14_M2 |
| 7 | 43 | GPIO1_B3 | UART4_TX_M2 |
| 9 | — | GND | |
| 11 | 139 | GPIO4_B3 | UART8_CTSN_M0, PWM15_IR_M1, I2S1_SDO2_M0 |
| 13 | 138 | GPIO4_B2 | UART8_RTSN_M0, PWM14_M1, I2S1_SDO1_M0, SPI0_CS0_M1 |
| 15 | 140 | GPIO4_B4 | UART9_TX_M1, PWM11_IR_M1, SPDIF0_TX_M1, I2S1_SDO3_M0 |
| 17 | — | +3.3V | Power |
| 19 | 33 | GPIO1_A1 | UART6_TX_M1, I2C2_SCL_M4, SPI4_MOSI_M2 |
| 21 | 32 | GPIO1_A0 | UART6_RX_M1, I2C2_SDA_M4, SPI4_MISO_M2 |
| 23 | 34 | GPIO1_A2 | UART6_RTSN_M1, I2C4_SDA_M3, PWM0_M2, SPI4_CLK_M2 |
| 25 | — | GND | |
| 27 | 23 | GPIO0_C7 | UART1_RTSN_M2, I2C6_SDA_M0, PWM6_M0, I2S1_SDI2_M1, SPI0_MISO_M0 / USB4_DP via R104 |
| 29 | 42 | GPIO1_B2 | UART4_RX_M2, SPI0_MOSI_M2 |
| 31 | 41 | GPIO1_B1 | SPI0_MISO_M2 |
| 33 | 44 | GPIO1_B4 | UART7_RX_M2, SPI0_CS0_M2 |
| 35 | 128 | GPIO4_A0 | UART9_RTSN_M1, I2S1_MCLK_M0, SPI0_MISO_M1 |
| 37 | — | SARADC_VIN2 | 1.8V analog input |
| 39 | — | GND | |

**Right Side (even pins 2–40):**

| Pin | GPIO# | GPIO Name | Alternate Functions |
|-----|---|---|---|
| 2 | — | +5.0V | Power |
| 4 | — | +5.0V | Power |
| 6 | — | GND | |
| 8 | 13 | GPIO0_B5 | UART2_TX_M0, I2C1_SCL_M0, I2S1_MCLK_M1 |
| 10 | 14 | GPIO0_B6 | UART2_RX_M0, I2C1_SDA_M0, I2S1_SCLK_M1 |
| 12 | 129 | GPIO4_A1 | SPI0_MOSI_M1, I2S1_SCLK_M0, UART9_CTSN_M1 |
| 14 | — | GND | |
| 16 | 37 | GPIO1_A5 | SPI2_MOSI_M0 |
| 18 | 40 | GPIO1_B0 | SPI2_CS1_M0 |
| 20 | — | GND | |
| 22 | 45 | GPIO1_B5 | UART7_TX_M2, SPI0_CS1_M2 |
| 24 | 35 | GPIO1_A3 | UART6_CTSN_M1, I2C4_SCL_M3, PWM1_M2, SPI4_CS0_M2 |
| 26 | 36 | GPIO1_A4 | SPI2_MISO_M0 |
| 28 | 24 | GPIO0_D0 | UART1_CTSN_M2, I2C6_SCL_M0, PWM7_IR_M0, I2S1_SDI3_M1, SPI3_MISO_M2 / USB4_DM via R106 |
| 30 | — | GND | |
| 32 | 136 | GPIO4_B0 | UART8_TX_M0, I2C6_SDA_M3, I2S1_SDI3_M0, SPI2_CS1_M1 |
| 34 | — | GND | |
| 36 | 130 | GPIO4_A2 | SPI0_CLK_M1, I2S1_LRCK_M0 |
| 38 | 133 | GPIO4_A5 | UART3_TX_M2, I2C3_SDA_M2, I2S1_SDI0_M0 |
| 40 | 137 | GPIO4_B1 | UART8_RX_M0, I2C6_SCL_M3, SPDIF1_TX_M1, I2S1_SDO0_M0, SPI0_CS1_M1 |

---

## 2. RADXA Zero 3W (RK3566)

| Property | Value | Source |
|---|---|---|
| PCB Dimensions (L×W) | 65 × 30 mm (bounding box) | [DXF CAD](https://dl.radxa.com/zero3/docs/hw/3w/radxa_zero_3w_2d_dxf.zip) |
| PCB Thickness | NOT FOUND | |
| Overall Height (H) | NOT FOUND | |
| Weight | NOT FOUND — not published | |
| Mounting Hole Dia | 2.82 mm (M2.5) | DXF verified |
| Power Input | 5V DC via USB-C or GPIO pins 2/4 | [Product Brief](https://dl.radxa.com/zero3/docs/hw/3w/radxa_zero_3w_product_brief.pdf) |
| Recommended PSU | 5V/2A (10W) | Same |
| Ambient Operating Temp | 0°C to 50°C | Same |
| SoC Throttle Temp | 85°C | Same |
| MIPI CSI | 1× 4-lane, 22-pin FPC connector (0.5mm pitch) | Schematic v1.11 |
| GPIO Header | Standard 40-pin through-hole, 2.54mm pitch (no castellations) | Radxa Wiki |

### Mounting Hole Positions (from DXF, origin at bottom-left)

| Hole | X (mm) | Y (mm) |
|---|---|---|
| 1 | 3.60 | 26.45 |
| 2 | 61.40 | 3.60 |
| 3 | 61.40 | 26.50 |
| 4 | 3.55 | 3.60 |

### Zero 3W — GPIO Pinout (40-pin, 2.54mm pitch)

Source: [Zero 3W Hardware Interface](https://docs.radxa.com/en/zero/zero3/hardware-design/hardware-interface)

**Left Side (odd pins 1–39):**

| Pin | GPIO# | GPIO Name | Alt Functions |
|-----|---|---|---|
| 1 | — | +3.3V | Power |
| 3 | 32 | GPIO1_A0 | UART3_RX_M0, I2C3_SCL_M0 |
| 5 | 33 | GPIO1_A1 | UART3_TX_M0, I2C3_SDA_M0 |
| 7 | 116 | GPIO3_C4 | PWM14_M0 |
| 9 | — | GND | |
| 11 | 97 | GPIO3_A1 | |
| 13 | 98 | GPIO3_A2 | I2S3_MCLK_M0 |
| 15 | 104 | GPIO3_B0 | |
| 17 | — | +3.3V | Power |
| 19 | 147 | GPIO4_C3 | SPI3_MOSI_M1, I2S3_SCLK_M1, PWM15_IR_M1 |
| 21 | 149 | GPIO4_C5 | SPI3_MISO_M1, I2S3_SDO_M1, PWM12_M1, UART9_TX_M1 |
| 23 | 146 | GPIO4_C2 | SPI3_CLK_M1, I2S3_MCLK_M1, PWM14_M1 |
| 25 | — | GND | |
| 27 | 138 | GPIO4_B2 | I2C4_SDA_M0, I2S2_SDI_M1 (USB2 via resistor mod) |
| 29 | 107 | GPIO3_B3 | I2C5_SCL_M0 |
| 31 | 108 | GPIO3_B4 | I2C5_SDA_M0 |
| 33 | 115 | GPIO3_C3 | I2S1_SCLK_RX_M2, UART5_RX_M1 |
| 35 | 100 | GPIO3_A4 | I2S3_LRCK_M0 |
| 37 | 36 | GPIO1_A4 | I2S1_SCLK_RX_M0 |
| 39 | — | GND | |

**Right Side (even pins 2–40):**

| Pin | GPIO# | GPIO Name | Alt Functions |
|-----|---|---|---|
| 2 | — | +5.0V | Power |
| 4 | — | +5.0V | Power |
| 6 | — | GND | |
| 8 | 25 | GPIO0_D1 | UART2_TX_M0 |
| 10 | 24 | GPIO0_D0 | UART2_RX_M0 |
| 12 | 99 | GPIO3_A3 | I2S3_SCLK_M0 |
| 14 | — | GND | |
| 16 | 105 | GPIO3_B1 | UART4_RX_M1, PWM8_M0 |
| 18 | 106 | GPIO3_B2 | UART4_TX_M1, PWM9_M0 |
| 20 | — | GND | |
| 22 | 113 | GPIO3_C1 | I2S1_SDO2_M2 |
| 24 | 150 | GPIO4_C6 | SPI3_CS0_M1, PWM13_M1, UART9_RX_M1, I2S3_SDI_M1 |
| 26 | — | NC | Not connected |
| 28 | 139 | GPIO4_B3 | I2C4_SCL_M0, I2S2_SDO_M1 (USB2 via resistor mod) |
| 30 | — | GND | |
| 32 | 114 | GPIO3_C2 | UART5_TX_M1, I2S1_SDO3_M2 |
| 34 | — | GND | |
| 36 | 103 | GPIO3_A7 | |
| 38 | 102 | GPIO3_A6 | I2S3_SDI_M0 |
| 40 | 101 | GPIO3_A5 | I2S3_SDO_M0 |

---

## 3. KHADAS VIM4 (A311D2)

| Property | Value | Source |
|---|---|---|
| PCB Dimensions (L×W) | 82.0 × 58.0 mm (±0.15) | [Spec Sheet PDF](https://dl.khadas.com/products/vim4/specs/new-vim4-specs.pdf) |
| PCB Thickness | 1.2 mm (±0.05) | [PCBA 2D Drawing](https://dl.khadas.com/products/vim4/blueprints/dxf/vim4-pcba-2d-v13.pdf) |
| Overall Height (H) | 11.5 mm (with tallest components) | Spec Sheet |
| Weight (bare board) | 31 g | Same |
| Weight (with heatsink) | ~48 g | Estimated |
| Mounting Holes | 4× M2 clearance, 2.20 mm dia | PCBA 2D Drawing |
| Mounting Pattern | Proprietary corner-mount (not RPi, not 30.5×30.5) | DXF available |
| Power Input | 9–20V DC via 4-pin Molex (1.25mm pitch) or USB-C PD | Spec Sheet |
| Recommended PSU | 12V/2A (24W) minimum via USB-C PD | Same |
| Idle Power | ~1.2W (0.1A @ 12V) | Same |
| Full Load Power | ~6.0W (0.5A @ 12V) | Same |
| SoC | Amlogic A311D2 — 4× A73 @ 2.2 GHz + 4× A53 @ 2.0 GHz | Same |
| RAM | 8 GB LPDDR4X @ 2016 MHz | Same |
| eMMC | 32 GB 5.1 | Same |
| WiFi | AP6275S, Wi-Fi 6, BT 5.1 | Same |
| HDMI OUT | Type-A, HDMI 2.1, 4K2K HDR | [Docs](http://docs.khadas.com/products/sbc/vim4/hardware/interfaces) |
| HDMI IN | Micro HDMI (Type-D), up to 4K@60fps | [HDMI Input Docs](http://docs.khadas.com/products/sbc/vim4/applications/hdmi-input-5.15) |
| NVMe M.2 | 2280 form factor, PCIe 2.0 ×1 (bottom side) | Spec Sheet |
| MIPI CSI #4 | 20-pin, 0.5mm pitch | Docs |
| MIPI CSI #5 | 30-pin, 0.5mm pitch, 4-lane (up to 16 MP) | Docs |
| MIPI-DSI / eDP | 40-pin, 0.5mm pitch FPC; 4-lane up to 1920×1200 DSI or 2560×1600 eDP | Docs |
| MCU | STM32G031K6 (power mgmt, boot media selection) | Spec Sheet |

### VIM4 Heatsink / Active Cooler

| Property | Value |
|---|---|
| Passive Heatsink | 81.0 × 49.1 × 8.9 mm, Al 6063 black anodized, ~17 g |
| Active Cooler | Adds 3705 PWM fan; total height ~13 mm above PCB |
| Fan Header | 4-wire PWM, 0.8mm pitch |

### VIM4 — 40-Pin GPIO Pinout (2.54mm pitch)

GPIO numbers valid for vendor kernel only (mainline differs).

Source: [40-Pin Header Docs](http://docs.khadas.com/products/sbc/vim4/applications/gpio/40pin-header)

| Pin | Name | GPIO# | Notes |
|-----|---|---|---|
| 1 | 5V | — | Power out |
| 2 | 5V | — | Power out |
| 3 | HUB_D4N | — | USB D- |
| 4 | HUB_D4P | — | USB D+ |
| 5 | GND | — | |
| 6 | VCCMCU | — | MCU 3.3V out |
| 7 | MCUBOOT0 | — | MCU boot mode |
| 8 | MCUSWDIO | — | MCU SWD data |
| 9 | GND | — | |
| 10 | ADC_CH6 | — | Analog input |
| 11 | VDD1V8 | — | 1.8V reference |
| 12 | ADC_CH3 | — | Analog input |
| 13 | SPDIFOUT | 420 | Digital audio out |
| 14 | GND | — | |
| 15 | UART_E_RX | 491 | UART-E receive (Android) |
| 16 | UART_E_TX | 490 | UART-E transmit (Android) |
| 17 | GND | — | |
| 18 | Linux_RX | — | Linux console RX |
| 19 | Linux_TX | — | Linux console TX |
| 20 | 3V3 | — | Power |
| 21 | GND | — | |
| 22 | I2CM_F_SCL | 501 | I2C-F clock |
| 23 | I2CM_F_SDA | 502 | I2C-F data |
| 24 | GND | — | |
| 25 | I2CM_A_SCL / SPI_A_SCLK | 466 | I2C/SPI clock (DT overlay) |
| 26 | I2CM_A_SDA / SPI_A_SS0 | 467 | I2C/SPI chip select |
| 27 | 3V3 | — | Power |
| 28 | GND | — | |
| 29 | I2S_SCLK1 | 447 | I2S bit clock |
| 30 | I2S_MCLK1 | 446 | I2S master clock |
| 31 | I2S_SDO1 | 449 | I2S data out |
| 32 | I2S_LRCLK1 | 448 | I2S frame sync |
| 33 | I2S_SDI1 | 450 | I2S data in |
| 34 | GND | — | |
| 35 | PWM_F | 492 | PWM output |
| 36 | SPI_A_MOSI | 464 | SPI master out / slave in |
| 37 | SPI_A_MISO | 465 | SPI master in / slave out |
| 38 | PWR_EN1 | — | Power enable |
| 39 | GPIO | 417 | General purpose |
| 40 | GND | — | |

---

## 4. Frames

### 4.1 TBS Source One V5 (5")

| Property | Value | Source |
|---|---|---|
| Wheelbase | 226 mm | [RaceDayQuads](https://www.racedayquads.com/products/tbs-source-one-v5-5-freestyle-long-range-frame) |
| Overall (approx) | ~254 × 114 × 51 mm | Google Shopping |
| Weight | 123.5 g | RaceDayQuads |
| Top/Mid Plate | 2.0 mm CF | [GetFPV](https://www.getfpv.com/tbs-source-one-v5-5-frame-kit.html) |
| Bottom Plate | 2.5 mm CF | Same |
| Arm Thickness | 6.0 mm CF | Same |
| Stack Mount | 30.5×30.5 (M3) **and** 20×20 (M2) + DJI Air Unit | [Lumenier](https://www.lumenier.com/products/tbs-source-one-v5-5-frame-kit) |
| Camera Mount | 19 mm stock gap (20 mm via TPU) | Printables |
| Standoffs | 30 mm and 22 mm | RaceDayQuads |
| Material | 3K carbon fiber | Retailers |
| Configuration | Wide-stance X | TBS |

### 4.2 SpeedyBee Mario 5 O4 (5")

| Property | XH (Stretched-X) | DC (Deadcat) | Source |
|---|:---:|:---:|---|
| Wheelbase | 226 mm | 227 mm | [SpeedyBee Official](https://www.speedybee.com/speedybee-mario-5-frame/) |
| Weight (no 3D prints) | 126 ±5 g | 129 ±5 g | Same |
| Weight (with 3D prints) | 167 ±5 g | 170 ±5 g | Same |
| Top Plate | 2.5 mm T300 3K CF | 2.5 mm T300 3K CF | Same |
| Middle Plate | 2.0 mm T300 3K CF | 2.0 mm T300 3K CF | Same |
| Bottom Plate | 2.5 mm T300 3K CF | 2.5 mm T300 3K CF | Same |
| Arm Thickness | 6.0 mm T300 3K CF | 6.0 mm T300 3K CF | Same |
| FC Mounting | 30.5×30.5 (M3) | 30.5×30.5 (M3) | Same |
| VTX Mounting | 20×20 (M2) / 25.5×25.5 (M2) | Same | Same |
| Camera Compat | 19 / 20 mm | 19 / 20 mm | Same |
| Motor Mount | 16–19 mm (Φ8 mm holes) | Same | Same |
| Internal Height | 23–31 mm | Same | Same |
| Max Prop | 5.1" | 5.1" | Same |

### 4.3 GEPRC Mark5 HD (5") — user cited "iFlight Mark5 HD"

*Note: "Mark5" is GEPRC product line — no "iFlight Mark5" exists.* iFlight equivalent is Cidora SL5 V2.1 HD.

**GEPRC Mark5:**

| Property | GEP-MK5X O3 (Squashed X) | GEP-MK5D O3 (Deadcat) | Source |
|---|:---:|:---:|---|
| Wheelbase | 225 mm | 230 mm | [GEPRC Official](https://geprc.com/product/gep-mk5x-o3-frame/) |
| Dimensions | 214×168×42 mm | 208×193×42 mm | Same |
| Weight | 141.9 g | 168.0 g | Same |
| Arm Thickness | 5.0 mm T300 3K CF | 5.0 mm T300 3K CF | Same |
| Stack Mount | 30.5×30.5 mm | 30.5×30.5 mm | Same |
| Camera | 20 mm | 20 mm | Same |
| Motor Mount | 16×16 / 19×19 mm | 16×16 / 19×19 mm | Same |
| Side Plates | 7075-T6 aluminum | 7075-T6 aluminum | Same |

**iFlight Cidora SL5 V2.1 HD (if needed):** 217 mm wheelbase, 156.1 g, 5.5 mm arms, 30×30 stack.

### 4.4 GX140 140mm (3")

| Property | Value | Source |
|---|---|---|
| Wheelbase | 140 mm | [xt-xinte](https://www.xt-xinte.com/JMT-GX140-Mini-Alien-3-Inch-140mm-Carbon-Fiber-FPV-Frame-Kit-4mm-Arm-with-Print-Accessories-for-FPV-Racing-Drones-Freestyle-DIY-p941667.html) |
| Weight | 53–60 g | xt-xinte / Amazon |
| Arm / Bottom Plate | 4.0 mm 3K CF | xt-xinte |
| Top Plate | 2.0 mm 3K CF | Same |
| Stack Mount | 20×20 mm | Same |
| Motor Mount | 12×12 mm (supports 1306–1608) | Amazon |
| Camera | 3D-printed adjustable, 0–40° tilt | Same |
| Standoffs | M3 × 25 mm aluminum (twin tower) | Same |
| Max Prop | 3" | Same |
| Overall L×W | NOT FOUND — only wheelbase published | |

### 4.5 GEPRC Mark4 7" / FPVDrone 295mm

| Property | Value | Source |
|---|---|---|
| Wheelbase | 295 mm | [Rotorama](https://www.rotorama.com/product/geprc-mark4-7) |
| Overall | ~226 × 266 mm (varies by source) | Same |
| Weight | 121 g | Same |
| Top/Bottom Plate | 2.5 mm (3 mm in some batches) | Same |
| Arm Thickness | 5.0 mm (V2: 6 mm) | Same |
| Stack Mount | 30.5×30.5 (M3) **and** 20×20 (M2) | Same |
| VTX Mount | 30.5×30.5 (M3) **and** 20×20 (M2) | Same |
| Motor Mount | 16×16 / 19×19 mm | Same |
| Camera | 19 mm (micro) | Same |
| Standoff Height | 25 mm (CNC 6061 Al) | Same |
| Battery | 4S 1800–6S 2200 mAh | Same |
| Max Prop | 7" | Same |

### 4.6 F450 Clone (450mm)

| Property | Value | Source |
|---|---|---|
| Wheelbase | 450 mm diagonal (motor-to-motor) | [B&H / DJI](https://www.bhphotovideo.com/c/product/1080059-REG/dji_cp_nz_000012_flame_wheel_f450_with.html/specs) |
| Weight (frame only) | ~280–282 g (no gear) | [Probots](https://probots.co.in/f450-quadcopter-frame-drone-glass-fibre-with-power-distribution.html) |
| Weight (full kit) | ~420 g (with gear) | Amazon |
| Arm Material | PA66+30GF nylon (hollow molded, NOT CF plate) | Various |
| Center Plates | Glass fiber composite | Probots |
| Stack Mount | **50 mm** hole pattern (APM/Pixhawk) — NOT 30.5 mm FPV standard | Same |
| Motor Mount | 16/19 mm, M3 | INVENTO |
| Max Prop | 8–10" | Multiple |

---

## 5. Flight Controllers

### 5.1 Matek H743-WLITE

| Property | Value | Source |
|---|---|---|
| PCB (L×W×H) | 44 × 29 × 14.5 mm (incl. headers) | [MatekSys](http://www.mateksys.com/?portfolio=h743-wlite) |
| Mounting Pattern | **25 × 25 mm** (NOT 30.5×30.5) | Same |
| Hole Diameter | **2 mm** (M2) | Same |
| Weight | 22 g (with extender board) | Same |
| Voltage Input | 6.8–30V (2S–6S) | Same |
| MCU | STM32H743VIH6, 480 MHz, 2 MB Flash, 512 KB RAM | Same |
| IMU | ICM42688-P | Same |
| Baro | DPS310 (I2C2, addr 0x76) | Same |
| OSD | AT7456E | Same |
| Blackbox | MicroSD card (SDIO) | Same |
| UARTs | **7** (all with signal inversion) | Same |
| PWM Outputs | **12** (all 5V tolerant except S2) | Same |
| ADC | VBAT (0–36V), Current (220A), RSSI, AirS, VB2, CU2 | Same |
| I2C | 2 ports (5V tolerant) | Same |
| CAN | 1 port (JST-GH-4P) | Same |
| BEC 1 | 5V/2A cont, 3A peak (FC, RX, OSD, cam, GPS) | Same |
| BEC 2 | 9V/12V/2A cont, 3A peak (VTX/cam; 12V via jumper) | Same |
| BEC 3 (Vx) | Adjustable 5V/6V/7.2V/8A cont, 10A peak (servos) | Same |
| BEC 4 | 3.3V/200 mA (baro/compass) | Same |
| RC Input | PWM/PPM, SBUS (RX6); CRSF/FPort with BRD_ALT_CONFIG=1 | Same |
| Dual Camera | Switchable via PINIO2 | Same |
| FW Targets | MATEKH743 (ArduPilot, INAV) | Same |

### 5.2 SpeedyBee F405 Mini Stack (20×20)

| Property | Value | Source |
|---|---|---|
| PCB (L×W×H) | 32 × 30 × 7.8 mm | [Manual](https://www.manualslib.com/manual/3291258/Speedybee-F405-Mini-Bls.html) |
| Stack Height | 14.2 mm (FC + ESC) | Same |
| Mounting Pattern | **20 × 20 mm** | Same |
| Hole Diameter | **3.5 mm** (M2/M3 compatible) | Same |
| Weight (FC only) | 9.6 g | Same |
| Weight (Stack) | 13.5 g | Same |
| Voltage Input | 3–6S LiPo | Same |
| MCU | STM32F405RGT6, 168 MHz | Same |
| Gyro | ICM-42688P | Same |
| Baro | DPS-310 | Same |
| OSD | AT7456E | Same |
| Blackbox | 8 MB onboard | Same |
| UARTs | **6** (1 dedicated BT, 1 ESC telemetry) | Same |
| BEC | 5V/2A (4 groups), 9V/3A, 3.3V/500mA, 4.5V/1A | Same |
| Bluetooth | Built-in (SpeedyBee App tuning) | Same |
| DJI Compatible | O3, Vista, RunCam Link, Air Unit V1 | Same |
| FW Target | SPEEDYBEEF405MINI | Same |

### 5.3 Radiolink F405

| Property | Value | Source |
|---|---|---|
| PCB Size | 30.5 × 30.5 mm | [Radiolink](https://www.radiolink.com/f405_new_specifications) |
| Mounting Pattern | 30.5 × 30.5 mm | Same |
| Hole Dia | NOT FOUND | |
| Weight | 9.5 g | Same |
| Voltage Input | 2S–6S LiPo (7.4–25.2V) | Same |
| MCU | STM32F405RGT6, 168 MHz | Same |
| Gyro | ICM42688 (6-axis) | Same |
| Baro | SPL06 | Same |
| OSD | AT7456E | Same |
| Blackbox | 128 MB onboard | Same |
| UARTs | **5** | Same |
| BEC | 3.3V/300mA, 5V/3A, 9V/3A (switchable) | Same |
| FW Targets | RADIOLINKF405 (BF), ArduPilot, INAV | Same |

### 5.4 GoolRC GF30F722 (JHEMCU)

| Property | Value | Source |
|---|---|---|
| PCB Size | 36 × 36 mm | [flymod.net](https://flymod.net/en/item/fc_gf30f722_30mm/17157) |
| Mounting Pattern | 30.5 × 30.5 mm | Same |
| Hole Dia | **4 mm** | Same |
| Weight | 8.8 g | Same |
| Voltage Input | 3–8S LiPo (11.4–36V) | Same |
| MCU | STM32F722RET6 | Same |
| Gyro | ICM-42688-P | Same |
| Baro | Yes | Same |
| OSD | AT7456E | Same |
| Blackbox | 16 MB onboard | Same |
| UARTs | **6** | [Betaflight JHEF7DUAL](https://betaflight-com.pages.dev/docs/wiki/boards/archive/JHEF7DUAL) |
| BEC | 5V/2.5A + 10V/2A (dual) | Same |
| FW Target | JHEF7DUAL (BF), INAV | Same |

### 5.5 SoloGood F722 60A Stack

| Property | Value | Source |
|---|---|---|
| PCB Size | 38.5 × 38.5 mm | [lxrcmodel](https://lxrcmodel.com/product/sologood-f722-60a-stack-icm42688p-4in1-esc-flight-controller-blheli_s-2-6s/) |
| Mounting Pattern | 30.5 × 30.5 mm | Same |
| Hole Dia | **4 mm** (M3) | Same |
| Weight (FC) | 8.1 g | Same |
| Stack Weight | ~23 g | Same |
| Voltage Input | 3–6S (11–30V) | Same |
| MCU | STM32F722RET6 | Same |
| Gyro | ICM42688P | Same |
| Baro | DPS310 | Same |
| OSD | AT7456E | Same |
| Blackbox | 16 MB | Same |
| UARTs | **6** (pin mapping in image-only manual) | Same |
| Motor Outputs | M1–M8 (X8 config) | Same |
| BEC | 5V/2A + 10V/2A | Same |
| FW Target | SOLOGOODF722 | Same |

### 5.6 MicoAir H743V2 (Standalone FC)

| Property | Value | Source |
|---|---|---|
| PCB (L×W×H) | 36 × 36 × 8 mm | [MicoAir Docs](https://micoair.cn/docs/MicoAir743V2-fei-kong-yong-hu-shou-ce) |
| Mounting Pattern | 30.5 × 30.5 mm | Same |
| Hole Dia | **4 mm** | Same |
| Weight | 10 g | Same |
| Voltage Input | 2–6S (6–27V) | Same |
| MCU | STM32H743VIH6, 480 MHz, 2 MB Flash | Same |
| Dual IMU | BMI088 + BMI270 | Same |
| Baro | SPL06 | Same |
| Mag | QMC5883L (onboard) | Same |
| OSD | AT7456E | Same |
| Blackbox | MicroSD (4 GB card included) | Same |
| UARTs | **8** | Same |
| PWM Outputs | **10** (1–8 support DShot/bidir) | Same |
| BEC | 5V/3A + 12V/3A | Same |
| Bluetooth | Built-in (UART8, 115200) | Same |
| DJI Compatible | O3/O4/O4 Pro direct plug (SH1.0-6P) | Same |
| FW Targets | MicoAir743v2 (AP), micoair_h743-v2 (PX4), MICOARAIR743V2 (INAV), BF | Same |

---

## 6. ESCs

### 6.1 Radiolink FLYCOLOR 55A 4in1

| Property | Value | Source |
|---|---|---|
| PCB (L×W×H) | 45 × 41 × 5.8 mm | Manuals |
| Weight | 15.8 g | Same |
| Mounting Pattern | 30.5 × 30.5 mm | Same |
| Hole Dia | M3 | Same |
| Voltage | 3S–6S (11.1–25.2V) | Same |
| Continuous Current | 55A per channel | Same |
| Burst Current | 65A | Same |
| Firmware | BLHeli_S (supports Bluejay, A-H-30) | Same |

### 6.2 SoloGood BLS8 60A 4in1

| Property | Value | Source |
|---|---|---|
| PCB Size | 41.5 × 42 mm | Desertcart |
| Weight | ~15 g | Same |
| Mounting Pattern | 30.5 × 30.5 mm | Same |
| Hole Dia | M3 (4 mm aperture) | Same |
| Voltage | 3S–6S (11–26V) | Same |
| Continuous Current | 55A per channel | Same |
| Max Current | 60A | Same |
| Firmware | BLHeli_S (J-H-30-16.7), Bluejay, bidir DShot | Same |

### 6.3 SpeedyBee BLS 35A Mini V2 (20×20)

| Property | Value | Source |
|---|---|---|
| PCB (L×W×H) | 35 × 35 × 5.5 mm | RaceDayQuads |
| Weight | 7.2 g | Same |
| Mounting Pattern | **20 × 20 mm** | Same |
| Hole Dia | **3.5 mm** (M2/M3) | Same |
| Voltage | 3S–6S | Same |
| Continuous Current | 35A per channel | Same |
| Burst Current | 45A (5 sec) | Same |
| Firmware | BLHeli_S (J-H-40) | Same |

### 6.4 HGLRC Specter 60A

*Note: Only produced as 4-in-1, not single ESC.*

**30×30 variant (8-bit):**

| Property | Value |
|---|---|
| PCB Size | 37 × 42.7 mm |
| Weight | ~14 g |
| Mounting Pattern | 30.5 × 30.5 mm (M3) |
| Voltage | 2S–6S |
| Current | 60A cont / 70A burst (10s) |
| Firmware | BLHeli_S (J-H-30) |

**20×20 variant (G071 32-bit):**

| Property | Value |
|---|---|
| PCB Size | 44 × 36 × 7 mm |
| Weight | 19.5 g |
| Mounting Pattern | 20 × 20 mm (M3) |
| Voltage | 3S–6S |
| Current | 60A cont / 65A burst (10s) |
| MCU | STM32G071 (128K) |
| Firmware | BL32 (SPECTER60_G_128) |

### 6.5 Readytosky 40A (Single)

| Property | Value | Source |
|---|---|---|
| PCB (L×W×H) | ~68–72 × 24–25 × 8–9 mm | Amazon |
| Weight | ~33–34 g (with BEC); ~26 g (OPTO) | Same |
| Mounting | Non-standard (generic ~3 mm holes) | Same |
| Voltage | 2S–4S (OPTO: 2S–6S) | Same |
| Current | 40A cont / 60A burst (10s) | Same |
| BEC | 5V/3A (standard version only) | Same |
| Firmware | Pre-programmed, **not user-flashable** | Same |

---

## 7. Motors

| Motor | Stator | Weight | Dia × H (mm) | Shaft | Mount Pattern | Screws | Voltage | KV |
|---|---|---|---|---|---|---|---|----|
| Axisflying AE2207 | 22×7 | 31.4 g | 27.2 × 33.3 | 5 mm | 16×16 mm | M3 | 6S | 1850 |
| NEEBRC 2807 V3 | 28×7 | 55 g | 34.5 × 20.4 can | 5 mm* | 16×16 or 19×19* | M3* | 3–6S | 1300 |
| HGLRC Specter 1804 | 18×4 | 13.3 g | 22.68 × 13.2 | 1.5 mm (M2 threaded) | 12×12 mm | M2 | 3–4S | 3500 |
| AKK 1407 | 14×7 | ~17 g | ~20 × 37 | 5 mm | 12×12 mm | M2 | 3–4S | 3500 |
| HGLRC Specter 1303.5 | 13×3.5 | 7.15 g | 17.53 × 11.7 | 1.5 mm (M2 threaded) | 9×9 mm | M2 | 2–4S | 5500 |
| Happymodel EX1103 | 11×3 | 3.8 g | 13.5 × 15.5 | 1.5 mm | 7 mm (T-Mount) | M1.4/1.6 | 1–2S | 11000 |
| Readytosky 2212 | 22×12 | 56 g | 28 × 28 × 46 | 6 mm | 16×19 mm | M3 | 3–4S | 920 |

*\* NEEBRC 2807: mounting pattern not confirmed from manufacturer — verify with seller (Woo-RC Store) before designing mounts.*
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

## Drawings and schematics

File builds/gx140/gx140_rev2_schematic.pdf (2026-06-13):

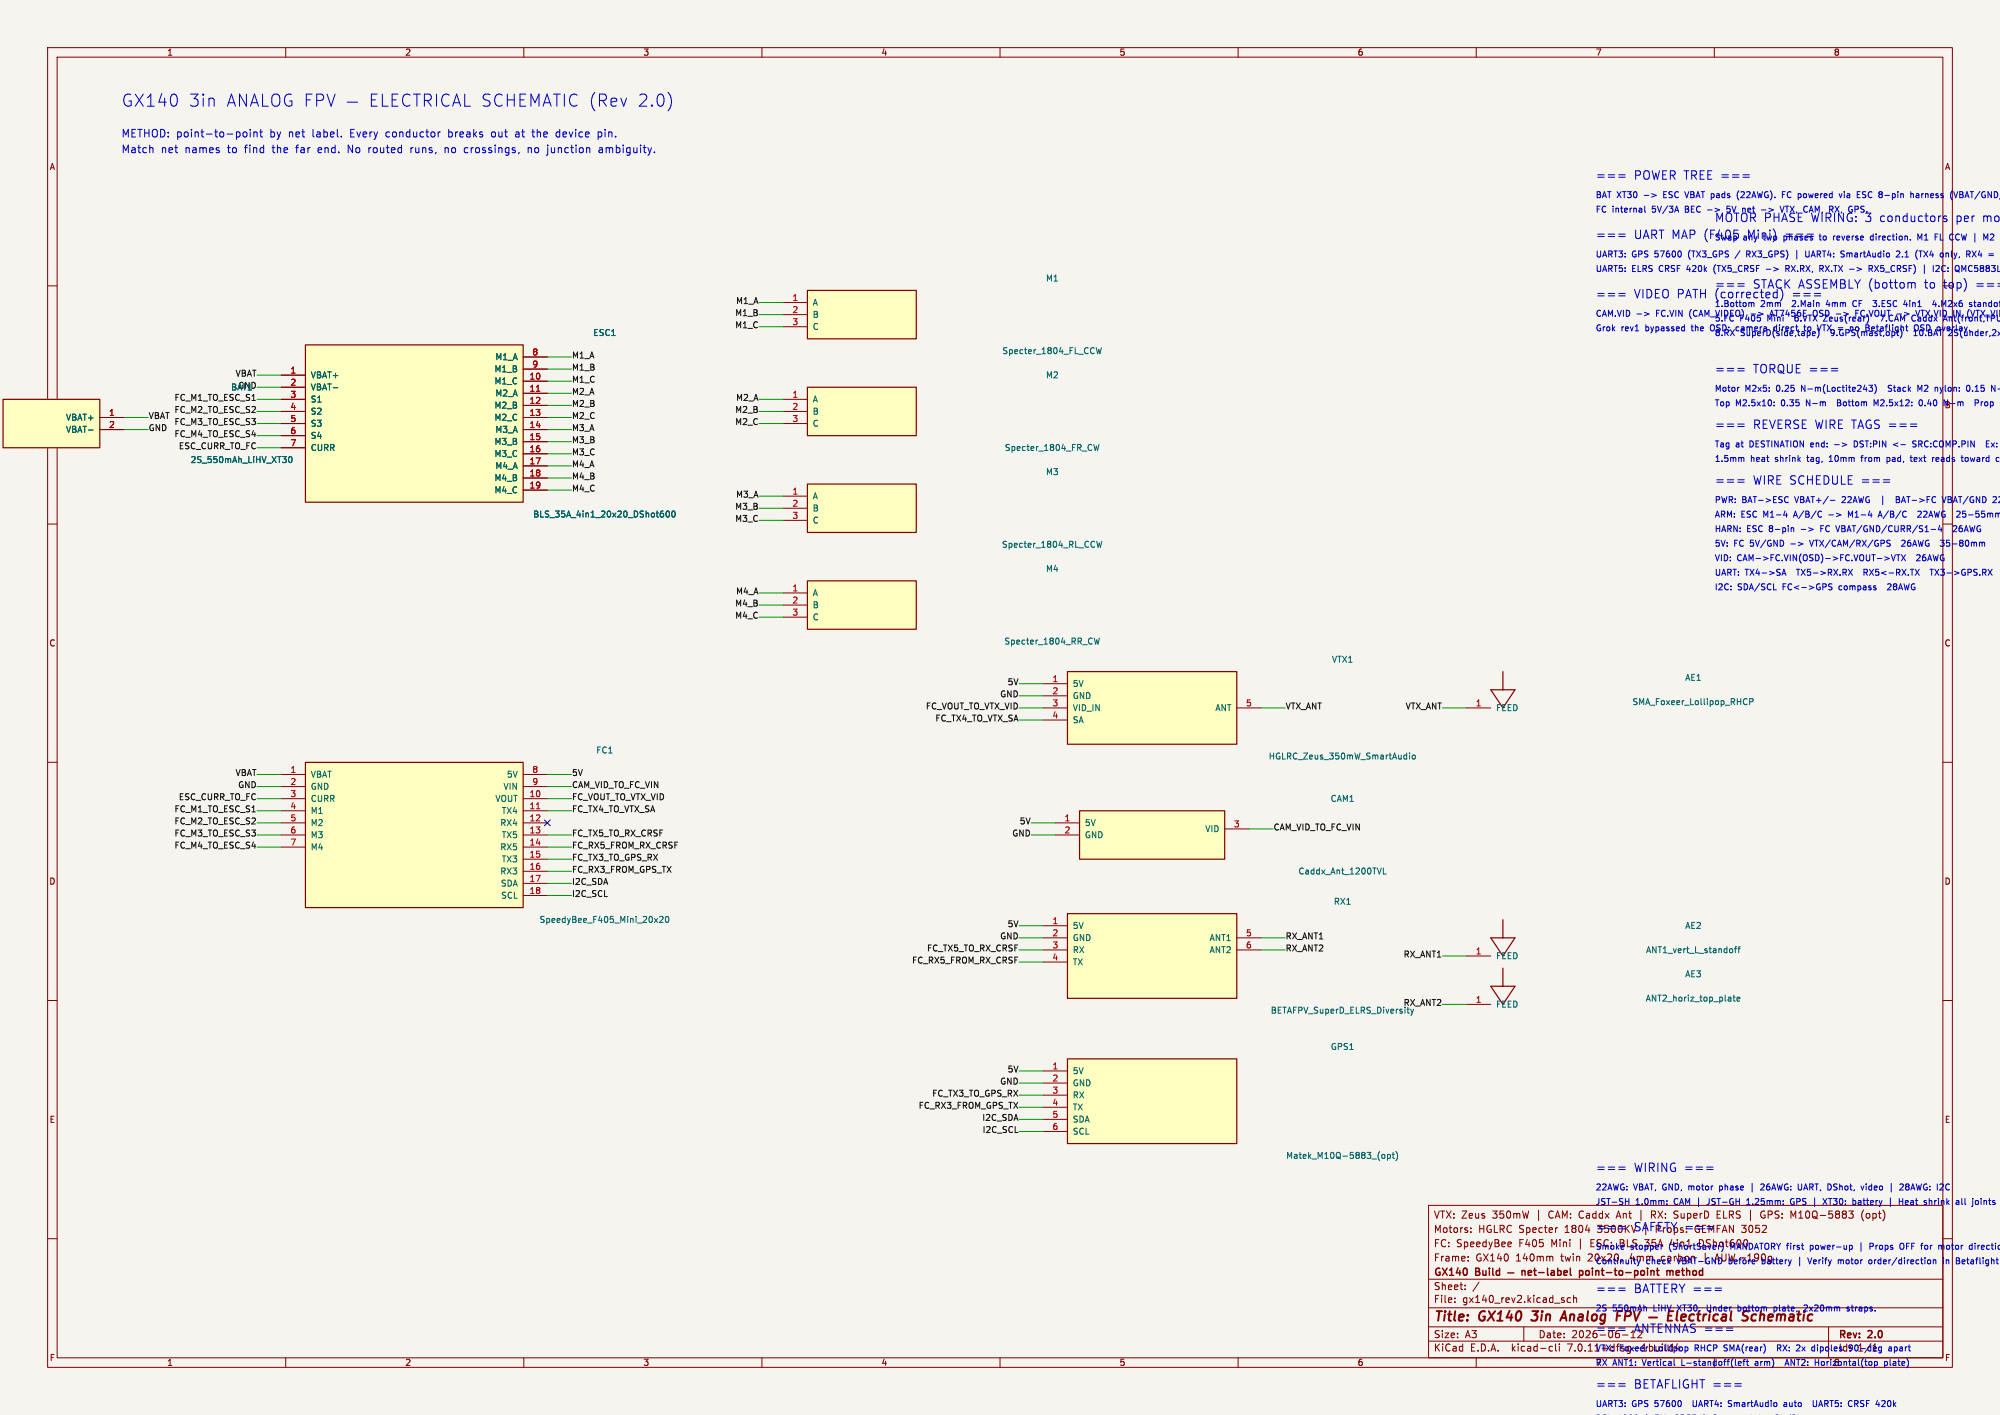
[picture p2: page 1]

GX140 3in ANALOG FPV þÿ ELECTRICAL SCHEMATIC (Rev 2.0)

22AWG: VBAT, GND, motor phase | 26AWG: UART, DShot, video | 28AWG: I2C

Id: 1/1 Title: GX140 3in Analog FPV þÿ Electrical Schematic

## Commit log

2026-06-13 Initial commit: GX140 3in Analog FPV Build Documentation
    [gx140.kicad_sch, gx140_clean.kicad_sch, gx140_complete.kicad_sch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]
2026-06-13 Replace old GX140 drawings and PDFs with rev2 KiCad schematic
    [gx140.kicad_sch, gx140_clean.kicad_sch, gx140_complete.kicad_sch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]
2026-06-13 Add GX140 engineering drawing set — 4-sheet package
    Sheet 1: Isometric exploded assembly view with all component locations
    Sheet 2: Top-down component placement with dimensions (140mm wheelbase)
    Sheet 3: Side section stack assembly with mounting methods and torque specs
    Sheet 4: Point-to-point wiring interconnect diagram with reverse wire tagging
    Includes KiCad schematic PDF plot and SVG source files for all drawings.
2026-06-13 Remove junk drawings — only KiCad schematic is the drawing
2026-06-13 Add engineering package text annotations to KiCad schematic
    Full wire schedule, reverse wire tagging method, stack assembly
    layers, torque specs, mounting notes, antenna layout, battery
    info, and Betaflight config — all in-schematic annotations.
    [gx140_rev2.kicad_sch]
2026-06-13 Reverse wire tag all net labels in KiCad schematic
    Rename all signal net labels to encode source-to-destination path:
    DSHOT_M1 -> FC_M1_TO_ESC_S1
    CAM_VIDEO -> CAM_VID_TO_FC_VIN
    VTX_VIDEO -> FC_VOUT_TO_VTX_VID
    TX4_SMARTAUDIO -> FC_TX4_TO_VTX_SA
    TX5_CRSF -> FC_TX5_TO_RX_CRSF
    RX5_CRSF -> FC_RX5_FROM_RX_CRSF
    TX3_GPS -> FC_TX3_TO_GPS_RX
    RX3_GPS -> FC_RX3_FROM_GPS_TX
    ESC_CURR -> ESC_CURR_TO_FC
    Every net label now reads as a reverse wire tag — at the
    destination pin you see exactly where the signal came from.
    [gx140_rev2.kicad_sch]
2026-06-13 Arrange schematic: components left, engineering notes right
    Shift all schematic symbols 40mm left to make room for notes.
    Move all text annotations to right side (X=335/360).
    Rename all net labels to reverse wire tagging convention
    (source->destination format).
    Layout: schematic (left) | engineering notes (right) on A3 sheet.
    Notes include power tree, UART map, video path, wiring schedule,
    reverse wire tag method, stack assembly, torque specs, battery,
    antennas, Betaflight config, and safety.
    [gx140_rev2.kicad_sch]
